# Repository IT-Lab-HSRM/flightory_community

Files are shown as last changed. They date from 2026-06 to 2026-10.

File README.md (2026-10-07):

# ✈️ Flightory Community Hub
### Experience Reports, Troubleshooting & General Help

A community knowledge base for everything Flightory — experience reports, troubleshooting guides, tips, and useful resources, built and maintained by students and enthusiasts.

### 🛠️ Our Story
During our drone project at the **Technical University Hochschule RheinMain**, we built a **Flightory Stallion VTOL** from the ground up. We quickly found that documentation was often insufficient, inconsistent, or scattered across many platforms. This repository was our answer: a structured, community-focused hub where knowledge and practical insights can be shared in one place.

Disclaimer: This is NOT official Flightory Documentation, but Experience gathered from the community <3

## 📁 Repository Structure

| Folder | Description |
|---|---|
| 🎓 [01_HSRM StallionVTOL_Our_Project](./01_HSRM%20StallionVTOL_Our_Project) | Our university project documentation following the build of a Stallion VTOL |
| 💡 [02_Tips, Learnings & Troubleshooting](./02_Tips,%20Learnings%20%26%20Troubleshooting) | Tips, best practices, Bug fixes, workarounds, issues |
| 🌐 [03_Community Projects & Knowledge](./03_Community%20Projects%20%26%20Knowledge) | External contributions & community findings |

> Each folder has its own README with more detail on what goes inside.

## 🔗 External Resources

We include external links when they provide meaningful value.

### 📄 Flightory Manuals
As found in a different GitHub Repo:
[github.com/complexorganizations/flightory-com](https://github.com/complexorganizations/flightory-com)

### 🏢 Official Flightory

| Resource | Link |
|---|---|
| Official Website – LW-PLA Print Settings | [flightory.com/lw-pla-print-settings](https://flightory.com/lw-pla-print-settings/) |
| Facebook Community Group | [facebook.com/groups/flightory](https://www.facebook.com/groups/flightory/) |
| Official Facebook Page | [facebook.com/flightoryuav](https://www.facebook.com/flightoryuav/) |
| Official YouTube Channel | [youtube.com/c/FLIGHTORY](https://www.youtube.com/c/FLIGHTORY) |
| Official Discord | [discord.com/flightory](https://discord.com/channels/1235173288150437929/1277936960970690603) |

### 🎬 Helpful Tutorials on YouTube

- [Flightory Talon 1400 Build Tutorial Part 1](https://www.youtube.com/watch?v=U0Qsgw7TUzI)
- [Flightory Talon 1400 Build Tutorial Part 2](https://www.youtube.com/watch?v=ay6Tz3RohFc)
- [Stallion VTOL Full Build Playlist](https://www.youtube.com/playlist?list=PL0V78eTdTTFGM4ZsZB-8frSqBhW0S1qe1)

Full Beginners Guide Stallion VTOL: 
- [Part 1](https://www.youtube.com/watch?v=75mRBMRqSeE&list=PL8VKXobKCFh9J2dTppRWEMae5zzevURrA)
- [Part 2](https://www.youtube.com/watch?v=D3_zBNBu3qo)
- [Part 3](https://www.youtube.com/watch?v=thHDy3jc1nU)
- [iNav Setup Stallion VTOL](https://www.youtube.com/watch?v=B3aNtYs5-dk)

### 💬 Interesting Reddit Communities

- [r/diydrones](https://www.reddit.com/r/diydrones)
- [r/drones](https://www.reddit.com/r/drones)
- [r/RCplanes](https://www.reddit.com/r/RCplanes)

### 🐙 Interesting GitHub Repos
- [/awesome-drone-engineers](https://github.com/brandonhimpfen/awesome-drone-engineers)

## 🤝 Who Can Contribute?

Everybody is welcome to contribute! 😊

Your Questions, Answers and personal experience can be shared via: 
- Issues
- Pull Requests

For more info see [03_Community Projects & Knowledge](./03_Community%20Projects%20%26%20Knowledge)

## 📝 Source Attribution

Each contribution must include a source reference. This can be helpful to get the content correct. 

**Format:**
```
Source: Personal / Facebook / Discord / Official Docs / Other (with link)
Post/Date (if available)
```

**Examples:**
```
Source: Personal experience, tested on ...
Source: Discord, link ...
Source: Facebook Group "Flightory Community", link: ...
```

## 📌 Notice

This repository is a work in progress, created as part of my bachelor's course at the **Technical University Hochschule RheinMain**. It will grow over time — both through our own findings and through your contributions.

If it looks a bit thin right now, that's expected. Stay tuned, share your experiences, and thank you for your understanding! 🙏

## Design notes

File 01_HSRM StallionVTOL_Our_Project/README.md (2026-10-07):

# 🚁 01 – HSRM StallionVTOL: Our Project

This folder documents our practical course project at the **Technical University Hochschule RheinMain (HSRM)**, where we built a **Flightory Stallion VTOL** system from the ground up.

It serves as a transparent record of our process — including what worked, what didn't, and everything we learned along the way.

Documents in this folder are organized across two practical courses (P1 and P2). 
The prefix in each filename indicates which course it belongs to, making the chronological progression easy to follow.

Our own troubleshooting tips and learnings are of course incoporated in [02_Tips, Learnings & Troubleshooting](/02_Tips,%20Learnings%20%26%20Troubleshooting)

## 📂 What You'll Find Here

- Build process and assembly notes
- Configuration and setup decisions
- Problems we encountered and how we solved them
- Lessons learned and personal takeaways

## 📁 Folder Structure  

| File | Description |
|---|---|
| 📷 [P1_pictures](./P1_pictures) | Pictures used in Part 1 of our documentation |
| 📦 [P1_stl_payload_case](./P1_stl_payload_case) | STL files for the payload box we've designed |
| 📷 [P2_pictures](./P2_pictures) | Pictures used in Part 2 of our documentation |
| 📝 [P1_experience_report](./P1_experience_report.md) | The first part of our journey (Wintersemester 2024/25) summed up |
| 🔗 [P1_links_parts_tutorials](./P1_links_parts_tutorials.md) | Links we found useful |
| 🛒 [P1_shopping_list](./P1_shopping_list.md) | Our shopping list for the first part |
| 📝 [P2_experience_report](./P2_experience_report.md) | The second part of our journey (Summersemester 2025) summed up |
| 📓 [P2_logbook](./P2_logbook.md) | An informal logbook of the second part, a detailed track record |
| 🛠️ [P2_repairguide](./P2_repairguide.md) | A small guide on how to repair the Stallion's tail after a crash |

## 📝 Source

All content in this folder is based on personal experience during the HSRM project.

```
Source: Personal experience, HSRM drone project 2024/25
```

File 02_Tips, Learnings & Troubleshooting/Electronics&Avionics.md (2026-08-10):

# Electronics & Avionics 

## Table of Contents
0. [General](#0-General)
1. [Flight Controller & ESC](#1-flight-controller--esc)
2. [Motors & Servos](#2-motors--servos)
3. [GPS & Receiver](#3-gps--receiver)
4. [Power & Battery](#4-power--battery)
5. [VTX & Camera](#5-vtx--camera)
6. [Thermal Management](#6-thermal-management)
7. [Electronics & Wiring](#7-electronics--wiring)

## 0. General

### No wiring documentation provided by Flightory (hsrm)
**Problem:** Flightory provides no guidance on wiring the electronics — only a note that there is enough space for them.

**Fix:** Use the individual component manuals (FC, ESC, GPS, receiver) to determine pin assignments. The ArduPilot VTOL wiring documentation is the most complete reference available. Community Discord is useful for specific connector questions.

---

### Almost no connectors are compatible out of the box (hsrm)
**Problem:** Nearly every connector in the build either didn't match, was missing, or had the wrong pin order. This affected:
- FC to ESC
- GPS module connector (JST-SH vs JST-GH mismatch)
- Motor cables to ESC
- Battery cables to charger

**Fix:**
- Have a stock of JST-SH, JST-GH, and XT60 connectors ready
- Expect to cut, re-pin, and re-solder most connections
- Cross TX→RX and RX→TX whenever connecting serial devices (GPS, receiver, telemetry)
- Verify pin order against both component manuals before soldering — "plug and play" rarely means what it implies

---

### Cable channels are too narrow for bundled cables (hsrm)
**Problem:** The fuselage cable channels are tight. Several cables broke during routing.

**Fix:** Bundle cables with heat-shrink tubing before routing — this protects individual wires and makes the bundle more rigid and manageable. Do not force cables through channels — if resistance is felt, remove and check for a blockage.

---

### Faulty component on delivery — check everything before assembly (hsrm)
**Problem:** One servo arrived defective and only failed during testing, requiring disassembly and replacement of already-installed parts.

**Tip:** Test all servos, motors, and ESCs on the bench before installation. A servo tester or the FC's output test mode is sufficient — this takes minutes and can save hours of rework.

---

## 1. Flight Controller & ESC

### Motors won't respond despite successful arm in Mission Planner (hsrm)
**Problem:** Mission Planner shows a successful arm status but motors remain completely silent at all throttle inputs.

**Cause:** No physical arm/disarm switch configured on the transmitter. Mission Planner can show "armed" in software while the transmitter has no channel assigned to trigger arming on the FC.

**Fix:** Configure a dedicated arm/disarm switch on the transmitter and link it to the correct ArduPilot arm function in Mission Planner. Once correctly assigned, set the switch to arm — motors should immediately spin up at idle and respond to throttle input.

> This was the single issue blocking all motor control from the previous semester. It took until this semester to identify and cost significant time.

---

### Pitch and roll axes inverted on first flight (hsrm)
**Problem:** After first takeoff, pitch and roll inputs produce the opposite of the expected response — pushing forward pitches backward, etc.

**Fix:** In Mission Planner, invert the relevant RC input channels or set the servo output to "reversed" for the affected axes. Check all axes on the ground before flight using the Mission Planner servo output monitor while moving sticks.

---

### SpeedyBee F405 Wing Mini — bricked after flashing iNAV (fb)
**Problem:** After flashing iNAV (target SPEEDYBEEF405WING), the FC stopped connecting. SpeedyBee app shows "Failed to Communicate with FC." No COM port or DFU visible in iNAV Configurator.

**Fix:** Disconnect the GPS module completely from the FC, then reflash. The GPS appears to interfere with the DFU/connection process on this board.

**Also:** Use **Zadig** to install the correct USB driver (STM32 Bootloader) in Windows if DFU mode isn't being recognised.

---

### SpeedyBee F405 Wing — DFU mode shows as "Unknown Device" (dc)
**Problem:** Holding BOOT button puts FC into DFU but Windows shows "Unknown Device." ImpulseRC Driver Fixer doesn't help.

**Fix:** The FC needs to show as "STM32 Bootloader" in Device Manager. Delete the unknown device, then use **Zadig** to install the correct WinUSB driver. Then retry flashing.

---

### JHEMCU F405 clone — is it compatible? (fb)
**Question:** Can I use a JHEMCU F405 clone instead of the SpeedyBee (which is out of stock)?

**Answer:** Yes, Any F405-class FC flashed with the correct iNAV or ArduPilot target will work the same way.

---

### 4-in-1 ESC current rating — is 50A enough for VTOL? (fb)
**Question:** ESC rated 50A but total current draw at transition showed 93A — is the ESC undersized?

**Clarification:** A 4-in-1 ESC rated 50A means 50A **per motor/channel**, not total. So a 3-motor VTOL on a 50A 4-in-1 = 150A total capacity. The 93A reading is the **total draw across all motors**, which means each motor was pulling ~31A — well within the 50A per-channel rating.

---

### ESC cutting out during transition / crash (fb)
**Problem:** ESC triggered protection cutout at 93A during VTOL-to-fixed-wing transition, causing loss of power and crash. ESC rebooted mid-air (startup beeps heard after crash).

**Possible causes:**
  * **Underpowered/wrong battery voltage** — 1300KV motors designed for 5S–6S being run on 4S won't produce enough thrust and motor will draw more current trying to compensate
  * **Weight** — overweight build means motors work harder at transition
  * **Loose battery connector** — a slightly loose XT60 can cause momentary power interruption that triggers ESC protection
  * **Wiring gauge** — undersized wires cause voltage sag under load

---

### External PDB with current meter for F405 Wing (fb)
**Question:** What external PDB can be used with SpeedyBee F405 Wing to see total amp draw in OSD?

**Answer:** There isn't really a clean external PDB solution that connects a current meter to the F405 Wing. The **F405 Wing already has a built-in PDB with current sensing** — use that. Connect your battery through the FC's power input and configure the current sensor in the flight software.

---

### F405 battery monitoring settings (Matek F405 Wing V2 vs V1) (fb)
**Question:** Are the battery monitoring settings in Mission Planner the same for V2 as V1?

*Note:* ArduPilot docs at: https://ardupilot.org/plane/docs/common-matekf405-wing.html
*(V2 settings not confirmed, check directly with Matek or ArduPilot forums for V2-specific BATT_AMP_PERVLT and BATT_VOLT_MULT values.)*

---

### Motors not spinning in iNAV — arming disabled (dc)
**Problem:** Motors go through boot beep sequence but won't spin. iNAV shows "Arming_Disabled_RC_link."

**Fixes:**
  * Check arming flags in iNAV — look at bottom status bar
  * RC link error = the flight controller doesn't see a radio receiver signal
  * Make sure receiver is bound and connected via correct UART
  * In iNAV Receiver tab, set correct UART and CRSF as connection type
  * Cross RX→TX and TX→RX between FC and receiver
  * Try ArduPilot if iNAV is unfamiliar — easier for first builds according to community

---

### ESC not communicating with FC — motors won't spin (dc)
**Problem:** 4-in-1 ESC connected but FC can't control motors.

**Root cause:** FC wasn't communicating with ESC. Missing telemetry/communication wire, or motor +/- wired backwards.

**Fix:** Check that FC is talking to ESC via correct pins. Swap positive and negative motor wires if motors don't spin. With a 4-in-1 ESC, ensure the communication cable is properly connected, not just the power wires.

---

### UART settings not saving in iNAV (dc)
**Problem:** UART 5 saves but after reboot the setting disappears.

**Fix (self-discovered):** Was using the slider as an on/off switch incorrectly. Check the iNAV documentation for the correct way to enable UARTs. Conflicting inputs can prevent saves.

---

### ESC (Lumenier/BLHeli_32) won't connect to BLHeli Suite (dc)
**Problem:** BLHeli Suite can't read or connect to ESCs.

**Fix:** Download BLHeli Suite from the correct source: https://sequremall.com/pages/blhelisuite32 and make sure you have the correct version. Also requires a **charged LiPo connected to the ESC** during configuration — USB power alone is not enough. Enable BLHeli passthrough in ArduPilot first.

---

### FC smokes / burns during full throttle test (dc)
**Problem:** SpeedyBee F405 Wing smoked during motor test at full thrust with 4S battery.

**Likely causes:**
  * Capacitor wired incorrectly (should be on battery pads, not elsewhere)
  * Poor solder joints — any exposed brass or cold joints can cause shorts
  * Having FC connected to PC via USB while also connected to battery can cause issues

**Fix:** Check all solder joints — exposed brass means a bad joint. Use paste flux to improve soldering. If the gyro chip is damaged the FC may be fried. An SMD soldering station can replace the IC if you have the skills.

---

### Motors pulsing when disarmed (SpeedyBee F405 + 4-in-1 ESC) (dc)
**Problem:** Motors pulse continuously when disarmed. ESC calibration appears to work but pulsing returns.

**Fix:** Set `Q_M_SAFE_DISARM` to 1 to stop pulsing when disarmed. If pulsing continues when armed, switch between DShot 300 and DShot 600 and redo ESC calibration. Community member resolved this by toggling between the two DShot settings.

---

### OSD disappears above 20–30% throttle (dc)
**Problem:** OSD flickers and disappears at higher throttle. Video feed unaffected.

**Cause:** Unfiltered voltage from the ESC causing noise on the OSD chip.

**Fix:** Add electrolytic capacitors to the ESC power pads. 470µF at 16V is a start (got the glitch threshold up to 40%). For a permanent fix on 4S, use 1000–1500µF rated at 25V or 35V (to handle full battery voltage safely). A solid common ground for all components also helps.

---

### Multiple BEC in parallel burned one immediately (dc)
**Problem:** Three BECs connected in parallel to the battery — one immediately burned out.

**Cause:** Multiple BECs in parallel fight each other on the output side due to slight voltage differences between them.

**Fix:** Don't connect multiple BECs in parallel directly. Use a single BEC with enough current capacity. For 6 small digital servos (EMAX ES08 size), a single 3–5A BEC is more than sufficient — actual current draw is much lower than stall current.

## 2. Motors & Servos

### Servo destroyed during testing — constrain movement before first test (hsrm)
**Problem:** During a servo test, a tilt rotor servo moved without input, hit the boom, stripped its gears, and was destroyed within seconds.

**Fix:** Before running any servo test, manually constrain the range of movement — hold the motor mount or temporarily block full travel. In ArduPilot/Mission Planner, set servo min/max limits before sending any test signals. Verify the servo is connected to the correct output channel first.

---

### What servo can I use instead of the recommended one? (dc)
**Answer:** Any servo with similar weight and torque rating will work. If the dimensions differ, you may need to modify the mounting bracket. Community-confirmed alternatives for Stallion:
  * Orbit Eris Digital Servo — 4.7kg, 0.10s, 8.5g metal gear
  * Corona SB9029 — 2.2kg, 0.10s, 12.5g
* Available at: https://alofthobbies.com/

---

### Motor not lifting VTOL — underpowered (dc)
**Problem:** 1300kv motor with 7" propeller can't lift a 2.25 kg VTOL.

**Fix:** Use PropCalc (https://www.ecalc.ch/xcoptercalc.php) to check your power/thrust figures before building. For VTOL, aim for at minimum 1:1 thrust-to-weight ratio at hover throttle. Check motor KV and prop size are matched to your battery voltage. *(See also section 4 regarding 4S vs 6S batteries for 1300KV motors).*

---

### Motor spinning wrong direction (dc)
**Fix:** Swap any two of the three motor phase wires to reverse rotation. For ESC-motor connections, use bullet connectors so you can easily swap wires without resoldering.

---

### Broken servo / servo spinning continuously (dc)
**Problem:** One servo spins continuously and won't hold position after centering attempt.
**Answer:** The servo is likely broken. Servos should spin to a stop position, not continuously. Replace it.

---

### ESC/motor smoking at 40% throttle (dc)
**Problem:** Motor and ESC started smoking at ~40% throttle.

**Possible causes:**
  * Short circuit somewhere — check all wiring for exposed solder pads and missing insulation
  * Cheap ESC with poor real-world ratings
  * Propeller hitting something and stalling the motor causes instant ESC burnout

**Fix:** Ensure all wiring is properly insulated with heatshrink. Add a capacitor on the battery pads. Verify ESC amperage rating matches motor requirements.

## 3. GPS & Receiver

### GPS not connecting — Matek M10Q-5883 + SpeedyBee F405 Wing + iNAV (fb)
**Problem:** GPS LED on, but iNAV shows 0 satellites, 0 total messages, Fix type: None. Ports configured with UART3 → Sensors → GPS, protocol UBLOX.

**Most likely cause:** TX/RX wires crossed incorrectly, or cable pinout incompatible between the two connectors.

**Checklist:**
  1. Confirm GPS TX → FC RX and GPS RX → FC TX (cross the wires)
  2. Verify the cable pinout against both the FC and GPS documentation — ready-made cables often have wrong pin order between JST-SH and JST-GH connectors
  3. Make sure "GPS for navigation and telemetry" is enabled in iNAV Configuration tab
  4. Test outdoors — GPS won't lock indoors

---

### GPS connector mismatch (SpeedyBee F405 Wing + Matek M10Q-5883) (dc)
**Problem:** FC uses JST-SH 1.0 but GPS uses JST-GH 6-pin — connectors don't match.

**Fix:** Insert wires into the GPS-side JST-GH connector and solder the other end directly to the FC. SpeedyBee intentionally provides a GPS cable with bare contacts for this reason. Pin order matters — verify pin-out against both manuals.

---

### GPS satellites = 0 indoors (dc)
* **Problem:** GPS shows 0 satellites when testing indoors.
* **Answer:** Normal — GPS often can't get a fix indoors due to building construction blocking signal. A GPS cold start can take 10–30 minutes on first use while it builds its almanac. After the first fix, subsequent lock-ons are much faster if the module has battery backup. Take it outside for proper testing.

---

### GPS freezing FC / servo outputs dropping to 0 (dc)
* **Problem:** Plugging in GPS causes all servo outputs and receiver channels to show 0 in Mission Planner. Unplugging GPS restores everything.
* **Cause:** Incorrect wiring — GPS pin order differs between brands. Ready-made cables can have wrong polarity.
* **Fix:** Verify pin-out carefully against both the FC and GPS manuals. Don't assume a ready-made cable is correct.

---

### Receiver not being detected by FC (Radiomaster Pocket + Matek R24D) (dc)
* **Problem:** Transmitter and receiver are bound, but FC shows no channel movement.
* **Explanation:** "Bound" only means the radio and receiver are talking to each other — it doesn't mean the FC sees the receiver yet.
* **Fix:** Cross RX→TX and TX→RX between receiver and FC. In iNAV, set the correct UART and choose CRSF as the protocol in the Receiver tab.

---

### ELRS receiver connected but arming disabled (Arming_Disabled_RC_Link) (dc)
* **Problem:** DJI O3 used as receiver on F405 Wing with iNAV — arming flag persists.
* **Fix:** Set the UART that the O3 is connected to for "SmartPort" / serial RX in iNAV configuration. Reference: https://speedybee.zendesk.com/hc/en-us/articles/23350373093787
* After fixing the RC link error, set up arming via a switch: go to the Receiver section in iNAV, use the channel auto-assign feature, and flip the switch you want to use for arming.

---

### TX16S external module power loop above 100mW (dc)
* **Problem:** Radiomaster Nomad TX module gets stuck in power loop when set above 100mW.
* **Answer:** The JR Bay interface is limited to ~100mW. This is a legacy hardware limitation — not a fault. For higher power levels (250mW, 1W, etc.), an **external battery via XT30** is required. The TX16S battery cover has a pre-marked knockout slot for the power lead.

## 4. Power & Battery

### 4S battery not enough for Stallion VTOL with 1300KV motors (fb)
**Problem:** Stallion VTOL with T-Motor F90 1300KV motors on 4S battery can't lift off — needed 100% throttle just to get a few inches up.

**Answer:** 1300KV is designed for 5S–6S. On 4S it doesn't have enough RPM to generate sufficient thrust, regardless of prop size.

**Fixes:**
  * Switch to **6S battery** (most recommended — night and day difference)
  * Or use **5S battery** as a minimum
  * Or change to higher-KV motors suited for 4S

---

### Battery for flight time estimation (fb)
**Rule of thumb:** If you know your cruising amp draw and battery capacity, divide capacity by amp draw for approximate hours.

**Example:** 10,000mAh battery at 4A cruise = ~2.5 hours. Check motor manufacturer specs for estimated cruise current at your voltage/prop combination.

---

### Batteries in wings — is it possible? (fb)
**Answer:** It has been done on other platforms (FX-78, Firefly-6 VTOL) but not practical for Flightory models. The wing profiles are too narrow for even 21700 cells, and the wings aren't designed to carry that structural load. A 3–4+ metre wingspan would be needed before wing batteries make sense.

---

### Wire gauge for VTOL builds (dc)
**Community guidance:**
  * Battery to FC/PDB: minimum **12 AWG** for VTOL, 14–16 AWG for non-VTOL
  * Motor to ESC: the wires that come with the ESC (typically 16 AWG) are fine — it's 3-phase and current is spread. 18 AWG is NOT enough for the recommended motors.
  * Reference: https://oscarliang.com/wires-connectors/

---

### Heavy 6S battery shifts CG dangerously forward (hsrm)
**Problem:** The new 6S 17 Ah battery is significantly heavier than the 4S pack. When mounted in the standard forward battery bay, the CG shifted well beyond the safe forward limit.

**Fix:** Add counterweight at the tail — approximately 350 g was required in this build to bring CG back within range. Alternatively, redesign the battery bay to mount the battery further rearward, or use a lighter 6S option. Always perform a CG test after any significant component change before attempting flight.

---

### 4S battery useful as accessory power source (hsrm)
**Tip:** Once replaced by the 6S pack for flight, old 4S batteries (XT60 connector) can be repurposed to power FPV goggles and a ground cooling fan. No need to dispose of or store them unused.

---

## 5. VTX & Camera

### Walksnail Avatar VTX not powering on (dc)
**Problem:** Walksnail Avatar HD Kit V2 doesn't power up. USB connection does nothing, no folders appear.

**Answer:** The VTX must be powered from the flight battery, not USB. USB will not power it.

**Fix:** Connect VTX power directly to battery pads on the FC (not a BEC output). Some FC BECs don't provide enough current to boot the VTX reliably.

---

### GM3 gimbal not moving (dc)
**Problem:** Walksnail video works but gimbal won't move.

**Fix:** The GM3 gimbal only works when oriented in the same direction as the VTX module. If the gimbal is flipped (e.g. to hang downward), it stops working. Flip both the gimbal AND the VTX module together to maintain orientation.

---

### VTX overheating on the ground (dc)
**Problem:** Walksnail electronics get very hot when not flying (no airflow).

**Fix:** Add a small 5V fan. The SpeedyBee F405 Wing has 4 x LED strip 5V pads that can power a small fan (up to ~0.5A draw). A 20x20mm or 25x25mm 5V fan is sufficient — just light airflow over the VTX heatsink is enough.

**Alternative:** Connect a 24V fan to the balance lead of a 6S battery, or a 12V fan to the 3S portion of the balance lead.

---

### DJI O3 OSD layout in goggles doesn't match Mission Planner setup (dc)
**Problem:** OSD layout keeps jumping around and doesn't correspond to what's set in Mission Planner.

**Fix:** Install WTFOS on both goggles and CADDX unit, then use the MPS DisplayPort on the UART. This resolved the issue.

---

### Lost video signal at 1 mile (Walksnail) (dc)
**Problem:** Video signal lost while flying ~1 mile away from home.

**Answer:** 1 mile (~1.5 km) is within the typical real-world range limit of Walksnail with stock antennas. There are many variables: interference, obstacles, antenna orientation. The community notes that losing signal at 1.5 km with stock setup is not unusual.

**Fix for reported crash:** The VTX was set to only 25mW instead of 700mW. Always verify your VTX power level before flying.

## 6. Thermal Management

### Battery and ESCs dangerously hot after extended hover (hsrm)
**Problem:** After multiple hover flight cycles, battery and ESCs reached temperatures too high to touch safely without protection.

**Cause:** Hover draws sustained high current — far more than forward flight. The 4-in-1 ESC has limited surface area for passive cooling without airflow.

**Fix:**
- Keep hover phases as short as possible — transition to forward flight quickly
- Allow cooling time between flights — do not immediately fly again after the battery or ESC is warm
- Monitor battery temperature as part of post-flight checks
- Plan active cooling (fan) for ground operation

---

### VTX overheating within minutes on the ground (hsrm)
**Problem:** Walksnail Avatar VTX reaches ~93°C within minutes during ground operation, triggering an overheat warning in the goggles. No active cooling on the ground means this happens before every flight.

**Fix:**
- Use a small 5V fan directed at the VTX heatsink during all ground operations — even brief setup time is enough to overheat it without airflow
- Mount the VTX where it receives maximum airflow in forward flight
- Old 4S batteries (no longer used for the drone) work perfectly to power the goggles and a cooling fan on the ground without draining the flight battery

## 7. Electronics & Wiring

### Modular electronics — recommended approach (hsrm)
Based on two semesters of experience, the following modularisation setup worked well and is recommended for future builds:

- **Motors:** Bullet connectors — each motor individually disconnectable without soldering
- **Servos:** Jumper cables to FC — removable without tools
- **Central electronics box:** FC and ESC in a single removable enclosure — full assembly can be pulled out and reinstalled in minutes
- **VTX / receiver:** Mount on a removable rail inside the fuselage — not tape

This approach significantly reduces fault-finding time and makes crash repair much faster. The one area that still needs a clean solution is a proper VTX and receiver mount — tape was used as a temporary fix and is not sufficient.

---

### SD card for error logging — essential, not optional (hsrm)
**Problem:** Two crashes produced no error logs because no SD card was installed in the FC.

**Fix:** Always have an SD card installed in the FC before any flight. In ArduPilot, logging is enabled by default when a card is present. Review logs after every flight — not just after incidents. Logs make root-cause analysis possible and dramatically reduce guesswork.

---

### WiFi connection to Mission Planner (hsrm)
**Tip:** A WiFi connection between the drone and a ground laptop running Mission Planner allows motor tests, servo trim, PFD monitoring, and flight data to be accessed remotely without a USB cable. Useful for pre-flight checks and post-flight data review. A second operator on the laptop is helpful but not strictly required once the setup is familiar.

---

### Real-time FPV video transmission vs onboard recording (hsrm)
**Finding:** Real-time video transmission to the goggles worked in flight, but the Walksnail system does not support simultaneous live transmission and recording to an external device. Onboard recording to an SD card in the camera worked reliably and produced usable footage. Plan storage accordingly — bring enough SD cards.

## 📝 Sources
- (dc) **Discord Group:** [Discord Flightory Group](https://discord.com/channels/1235173288150437929/1277936960970690603) 
- (fb) **Facebook Group:** [facebook.com/groups/flightory/](https://www.facebook.com/groups/flightory/)
- (hsrm) **Own personal experience** Made during Wintersemester 24/25 (HochschuleRheinMain)

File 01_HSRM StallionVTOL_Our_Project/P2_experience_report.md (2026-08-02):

# 🚁 Stallion VTOL – Final Project Report

*HSRM – Avionics Module · Summer Semester 2025*

# *The Dream of (Horizontal) Flight*

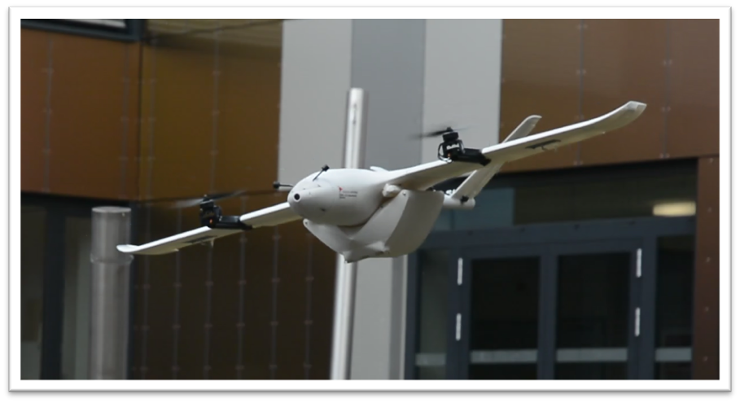
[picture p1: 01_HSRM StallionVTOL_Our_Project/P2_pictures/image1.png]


## Table of Contents

1. [Introduction & Goals](#introduction--goals)
2. [Technical Background](#technical-background)
3. [What We Did & What We Found](#what-we-did--what-we-found)
4. [Summary](#summary)
5. [Open Points & Outlook](#open-points--outlook)
6. [Sources & References](#sources--references)

## Introduction & Goals

This project picked up directly where the previous semester's UAV build left off. The Stallion VTOL was mechanically and electronically complete, but a remaining software issue was preventing actual flight. The goal this semester was to resolve that, get the drone properly airborne, and take the whole system a step further.

**Concrete objectives:**

- **Finalise flight capability** — systematic fault-finding and resolution of the software issues blocking motor control
- **Electronics modularisation** — clean, maintainable wiring with clear separation of functional modules
- **Flight testing & parameter tuning** — structured test flights including tuning for hover stability and transition to forward flight
- **Forward flight** — first controlled forward flight passes to assess horizontal flight behaviour
- **Technical optimisation assessment** — evaluate the real-world impact of our component upgrades (motors, props, CG)
- **Payload flight tests** — determine maximum useful payload through defined load tests, assessing stability and power consumption under load
- **Autonomous flight exploration** — set up PC-based mission planning and run initial automated flight sequences (e.g. waypoint missions)
- **Documentation** — complete technical documentation of all systems, work steps, tests and results as a foundation for future development

## Technical Background

The Stallion VTOL from last semester's project, with the following installed components:

| Component | Specification |
|---|---|
| Motors | T-Motor Velox Victory V3008 1350KV |
| Battery | Zeee 4S LiPo 14.8V 120C 7200mAh XT90 |
| Flight Controller | T-Motor F7 FPV FC |
| ESC | T-Motor F55A Pro II 4-in-1 2S–6S DShot BLHeli32 |
| Servos | GDW DS041MG / Corona Servo CS929MG |
| LEDs | SpeedyBee Programmable 2812 Arm LEDs |
| Propellers | Gemfan CL 8040 Cinelifter 3-blade 8" |
| Transmitter | RadioMaster Zorro ELRS |
| Receiver | Matek ELRS 2.4G Dual |
| FPV System | Walksnail Avatar HD Kit V2 (Dual Antenna) |
| Goggles | Walksnail Avatar HD FPV Goggles L |
| Body | Lightweight PLA (3D printed) |

The project benefited significantly from the support of the IT lab at HSRM — tools, chargers, cables, adapters, and workshop equipment were all on hand.

Picking up from last semester also meant carrying forward hard-won knowledge across electronics, CAD, ArduPilot configuration, ELRS firmware, Mission Planner, and soldering. These skills were essential from day one.

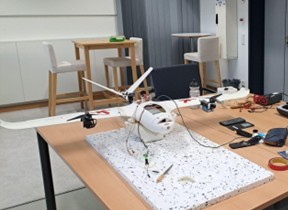
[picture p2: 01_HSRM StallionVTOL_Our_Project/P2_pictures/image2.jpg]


## What We Did & What We Found

### 1. Project Kickoff & Goal Definition
We started the semester by laying out everything that still needed doing. A to-do list was compiled, project goals were defined around modularisation, flight readiness, and stability, and the wiring was tidied up with a rough concept sketch to guide the work ahead.

### 2. Motor Activation — First Technical Breakthrough
The first real hurdle was getting the motors to actually respond. Despite Mission Planner showing a successful arm indication, the motors stayed silent — it turned out a physical arm/disarm switch had never been configured on the transmitter. Once we added the switch and linked it to the correct ArduPilot function, everything clicked into place: the system armed, the motors spun up at idle, and throttle inputs from the transmitter produced the expected response. It was the first time the full control chain had worked end to end.

### 3. Flight Test 1 — First Hover
The drone lifted off for the first time. In the air it was clear that the pitch and roll axes were inverted, which made control awkward, and strong oscillations around the yaw axis made yaw particularly difficult to manage. Despite all of that, the pilot managed to complete several takeoffs and landings without causing any structural damage — a promising start given the state of the parameters.

### 4. Battery & Thrust Analysis
In parallel with the flight work, we ran a proper analysis of the power system to understand what we were actually working with. A luggage scale was ordered for thrust measurements and weight calculations were done to assess whether the planned new battery was even feasible. The results confirmed the system had enough headroom — at 80% throttle the three motors together produce 7.79 kg of thrust at 124.5 A total draw, and cruise at 60% throttle sits around 61.5 A. One important constraint: 100% throttle is only sustainable for roughly 8 seconds, so hover and climb need to be achievable at well below that. With the current 4S setup the all-up weight came to 3.236 kg; switching to the new 6S 17 Ah battery would push that to 4.533 kg — still within the thrust envelope, but leaving less margin.

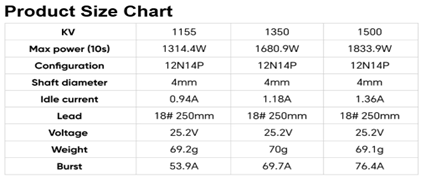
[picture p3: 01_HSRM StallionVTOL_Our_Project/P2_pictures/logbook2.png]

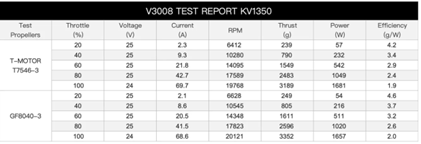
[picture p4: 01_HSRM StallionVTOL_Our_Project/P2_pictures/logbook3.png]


| Condition | Thrust | Current Draw |
|---|---|---|
| 80% throttle (max usable) | 7.79 kg | 124.5 A |
| 60% throttle (cruise) | — | 61.5 A |

| Component | Weight |
|---|---|
| Empty drone | 2.203 kg |
| Cargo case | 0.480 kg |
| Current battery (4S) | 0.553 kg |
| **Current AUW** | **3.236 kg** |
| With new 6S battery (1.85 kg) | **4.533 kg** |

### 5. Flight Test 2 — Parameter Tuning
The second flight was conducted in windy conditions, but the improvement over the first was immediately obvious. The control axes were no longer inverted, yaw behaviour was significantly better, and the drone handled multiple flight cycles without issue. The tuning was clearly working. Two things still needed attention: the tail servos were making audible overload sounds under load, signalling they needed to be replaced, and yaw still drifted slightly back when the stick was released. Post-flight, the battery and ESCs were hot enough that touching them without protection wasn't an option — thermal management was flagged as an open concern.



### 6. CAD Work & Parameter Optimisation
Between flights we used the time to design a landing gear and an enclosure for the ESC and flight controller in Fusion 360. Parameters were also refined further based on what the test flights had shown.

### 7. Flight Test 3 — Two Crashes
The third session started well but ended badly, twice. During a landing the drone simply fell out of the air after switching from QStabilize to QHover at about 2 m — motors cut out completely, the cargo case took the brunt of the impact, and the battery was found warm and unevenly discharged. No structural damage, but the suspected cause was thermal or voltage-related. The second crash was more dramatic: immediately after takeoff in QHover, the drone yawed hard toward the pilot without any stick input and accelerated forward. It hit a bench, the pilot, and a sign stand before the emergency stop was triggered. The most likely explanation was a GPS position mismatch — the pre-flight GPS check had been disabled for test purposes, and the FC may have tried to correct to a position it had never actually confirmed. The outcome was significant structural damage: tail, servo arm, propellers, and wing surfaces all needed attention.
Thankfully the pilot was not injured albeit a bit shaken. 

### 8. Damage Documentation & Safety
Every piece of damage was photographed and logged. We also used this moment to create a proper pre-flight checklist — something that should have existed earlier — to make sure the conditions that led to both crashes couldn't repeat themselves.

### 9. Repair & Modularisation
Damaged parts were removed and either reprinted or reordered. The repair became the natural moment to finally carry out the electronics modularisation we'd been planning. Motors were rewired with bullet connectors so each one is individually disconnectable; servos were connected via jumper cables for easy removal from the FC; and a central electronics box was built to allow the whole electronic assembly to be pulled out and reinstalled quickly. The tail was fully rebuilt, wing surfaces were filled and sanded, and the wiring was re-routed cleanly throughout. 

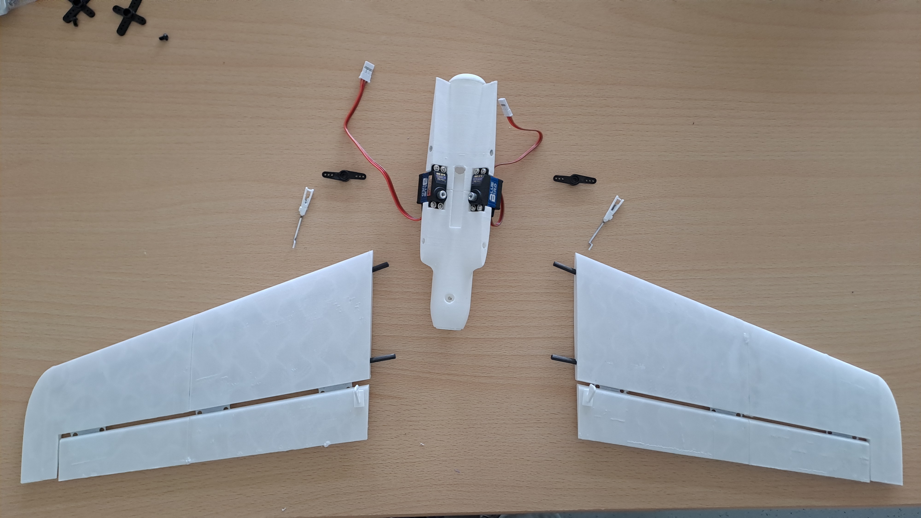
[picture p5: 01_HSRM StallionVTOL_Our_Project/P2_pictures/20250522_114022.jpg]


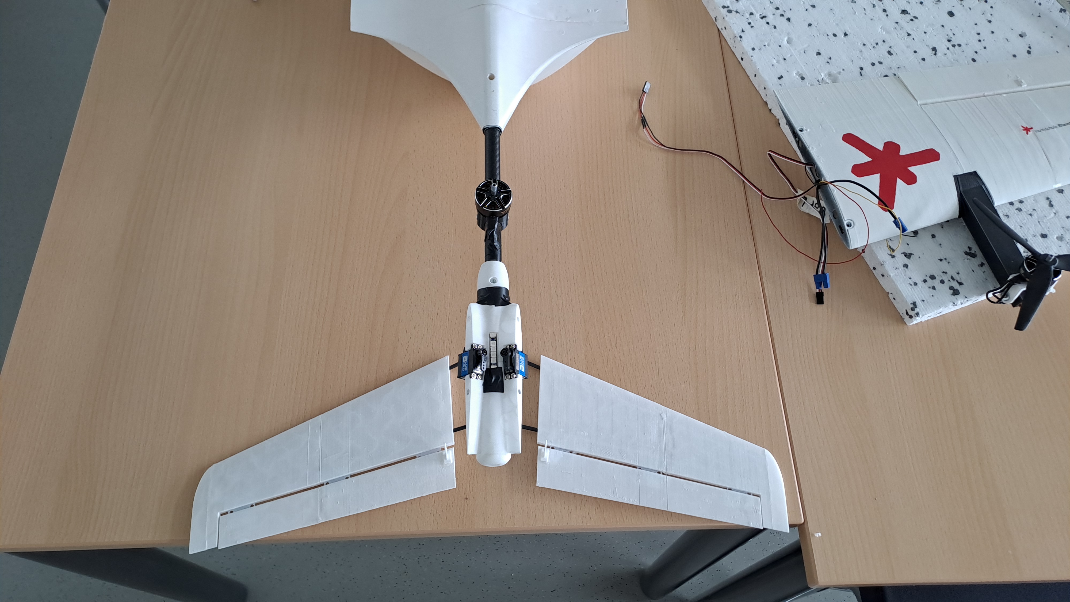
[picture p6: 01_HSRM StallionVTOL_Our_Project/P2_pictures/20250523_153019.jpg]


### 10. VTX Integration
With the new tail assembled and the electronics modularised, the VTX was connected and successfully paired with the FPV goggles. The battery hatch was modified to accommodate the larger 6S battery. One issue that became apparent immediately: the VTX runs extremely hot during ground operation, reaching temperatures that triggered an overheat warning in the goggles within minutes. Active cooling on the ground is essential before any flight. On a more positive note, the older 4S batteries that were no longer needed for the drone turned out to work perfectly as a power source for the goggles.

### 11. Further Build & Electronics Finalisation
The ESC/FC enclosure and landing gear were printed and installed. The VTX, receiver, and camera were all mounted on a removable rail to use the fuselage space efficiently. An SD card for error logging was added to the FC, and a second SD card for video recording was installed in the camera and tested successfully — real-time video transmission wasn't possible, but onboard recording worked well. A WiFi connection to Mission Planner was set up, enabling motor tests, servo trim, and flight data to be accessed remotely from a ground PC.

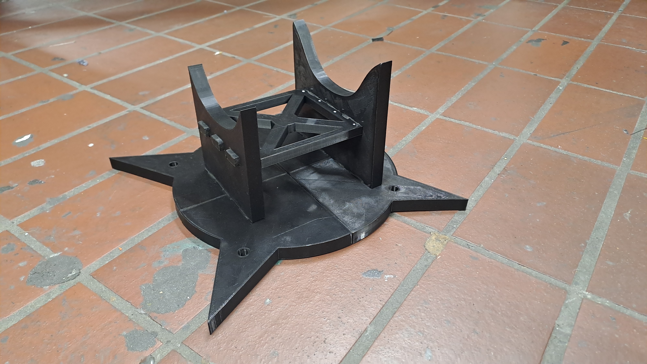
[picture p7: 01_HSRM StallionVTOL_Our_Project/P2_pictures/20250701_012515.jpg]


### 12. New Battery Integration & CG Testing
Integrating the new 6S 17 Ah battery required modifications to the battery bay to get it to fit. The heavier battery shifted the centre of gravity significantly forward, and a CG test confirmed that around 350 g of counterweight was needed at the tail to bring it back within the safe range. Despite the added mass, the drive system had enough thrust to remain viable for flight.

### 13. Flight Test 4 — Model Airfield (Crash)
The fourth test flight, conducted at a model airfield, ended in a crash immediately after takeoff. At first the drone didn't respond to throttle input at all despite a linear increase in the command — then motor output jumped suddenly to 100%, the impulse was far too abrupt for the flight controller to manage, and the drone flipped. Damage was sustained to the tail and parts of the fuselage, though the electronics appeared undamaged. The most likely causes are a combination of the heavy battery shifting the CG to a critical position, a possible software or signal issue between transmitter and receiver, and VTX-related RF interference — the VTX had already run hot before takeoff.

### 14. Repair Documentation
All damage from the airfield crash was documented and a detailed repair guide produced to bring the drone back to its previous state — see [Repair Guide](P2_repairguide.md).

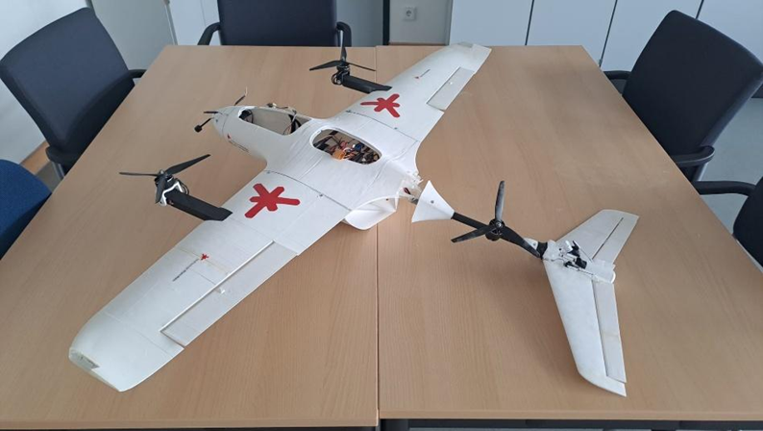
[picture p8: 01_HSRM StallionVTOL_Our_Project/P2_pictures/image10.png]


## Summary

A modular UAV system was developed, built, and tested across multiple flight phases this semester. Key milestones and findings:

**What worked:**
- Motors activated and responding to throttle after arm switch was configured
- Stable hover achieved through parameter tuning — from strong oscillations on the first flight to clean, controlled hover
- Full modularisation of electronics completed
- SD card error logging and video recording both functional
- WiFi Mission Planner connection successful

**What didn't go to plan:**
- Significant thermal load on battery and ESCs during extended hover — active cooling is needed
- Two crashes from thermal overload and GPS-related issues caused structural damage that required a full repair cycle
- Final flight test ended in a flip — likely a combination of weight, CG, thermal interference, and a motor response anomaly

**Where things stand:** The drone is currently damaged and not airworthy. A full repair is required before further flights can be conducted.

## Open Points & Outlook

**Immediate next steps:**
1. Full repair of crash damage (tail, fuselage segment) — see [Repair Guide](P2_repairguide.md)
2. Evaluate whether the current 6S 17 Ah battery is viable or a lighter option should be used
3. Alternatively: structural modifications to handle the battery weight and keep CG stable

**Once repaired:**
- Hover flight tests to verify stability
- Transition to forward flight with VTX/FPV
- First autonomous waypoint missions via ArduPilot Mission Planner

**Longer-term potential:**
- Integration of mission-specific sensors (surveying, monitoring, inspection)
- Design of a V2 airframe optimised for the challenges identified this semester:
  - Larger fuselage for heavier batteries
  - More powerful drive system
  - Additional interior space for payload or sensors

The project has genuine development potential — both in the academic context and toward real-world application. A clear strategic direction for the next team will be essential to make the most of what's been built and learned.

## Sources & References

- [T-Motor Velox V3008 motor data](https://www.mepsking.shop/tmotor-velox-v3008-cinematic-fpv-drone-motor.html)
- [ArduPilot — QuadPlane VTOL Tuning](https://ardupilot.org/plane/docs/quadplane-vtol-tuning-process.html)
- [ArduPilot — Tilt Vectored Yaw Tuning](https://ardupilot.org/plane/docs/tilt-vectored-yaw-tuning.html)
- [ArduPilot — Tilt Rotor Guide](https://ardupilot.org/plane/docs/guide-tilt-rotor.html)
- [ArduPilot — ESC Calibration](https://ardupilot.org/plane/docs/quadplane-esc-calibration.html)
- [ArduPilot — QuadPlane Parameters](https://ardupilot.org/plane/docs/quadplane-parameters.html)
- [ArduPilot — QuadPlane Flight Modes](https://ardupilot.org/plane/docs/quadplane-flight-modes.html)
- [ArduPilot — QuadPlane Tips](https://ardupilot.org/plane/docs/quadplane-tips.html)
- [Flightory — Stallion](https://flightory.com/product/stallion/)
- [Flightory — Stallion VTOL](https://flightory.com/product/stallion-vtol/)
- [YouTube — Stallion VTOL build reference 1](https://www.youtube.com/watch?v=FiyyzRG6oog)
- [YouTube — Stallion VTOL build reference 2](https://www.youtube.com/watch?v=IFvLQy3KrKs)
- [Oscar Liang — Walksnail Avatar FPV Setup](https://oscarliang.com/setup-avatar-fpv-system/)
- [SpeedyBee F405 Wing FC](https://www.speedybee.com/speedybee-f405-wing-app-fixed-wing-flight-controller/)

---

*Source: Personal experience, HSRM Avionics project, Summer Semester 2025*

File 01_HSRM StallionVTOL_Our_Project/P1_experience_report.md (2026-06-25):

# 🚁 Building the Stallion VTOL – Our Experience Report

*O. Alobaid, M. Daoud Agha, C. Diffenhard, O. Weigelt*

*HSRM – Unmanned Aerial Vehicles Module · Winter Semester 2024/2025*

## Table of Contents

1. [The Idea](#the-idea)
2. [What Flightory Gives You](#what-flightory-gives-you)
3. [Our Optimizations](#our-optimizations)
4. [How We Approached the Build](#how-we-approached-the-build)
5. [Assembly – What Actually Happened](#assembly--what-actually-happened)
6. [Challenges During Construction](#challenges-during-construction)
7. [Electronics Assembly](#electronics-assembly)
8. [Programming with ArduPilot](#programming-with-ardupilot)
9. [Ground Test Results](#ground-test-results)
10. [Final Thoughts](#final-thoughts)
11. [Thanks](#thanks)

## The Idea

We are four students who set out to build a 3D-printed Stallion VTOL drone based on Flightory's design — but not just replicate it. From the start, we wanted to push it further. Our main goal was to increase the drone's payload capacity, and to do that we designed a cargo case that can be transported securely beneath the aircraft. This meant rethinking parts of the structure, optimizing several components, and dealing with a lot of challenges we didn't fully anticipate going in.

## What Flightory Gives You

The Stallion VTOL is a tiltrotor drone built on a tricopter layout — two tilting front motors and one fixed rear motor. It's made from lightweight materials like LW-PLA and PETG, spans 1,340 mm, measures 990 mm in length, and cruises at 60–70 km/h with a takeoff weight of 2,000–3,000 g according to Flightory.

Flightory provides STL and STEP files for printing, a build guide, and a recommended parts list:

| Component | Recommendation |
|---|---|
| Motors | Emax ECOII 2807 1300KV or T-Motor F90 1300KV |
| Propellers | 7×4, 7×5, or 7×6 (2× CCW, 1× CW) |
| Servos | PowerHD 1810MG or GDW DS041MG |
| ESC | Emax Formula 45A BLHeli32 or Lumenier 51A |
| Battery | 4S Li-Ion max. 4S3P 10.5 Ah or comparable LiPo |
| Lighting | WS2812 ARM LED strips |
| Bearings | 3×8×4 mm flanged bearings ×2 |
| Hardware | M3 screws, nuts, washers |

We didn't stick to all of these — more on that below.

## Our Optimizations

### Cargo Case
We designed a case in Autodesk Fusion 360 that slides onto a rail system we modeled directly into the fuselage. The whole thing is 3D printed to keep it as light as possible while still being structurally solid.

### Motors
We went with more powerful motors — 23.4 g heavier per unit than the recommended ones, but delivering 621.9 W more power each. The extra current draw is compensated by the upgraded battery.

### Battery
Our batteries are 90 g heavier than the standard option but offer 2,200 mAh more capacity and a 20C higher discharge rate. The idea was to maintain decent flight time despite the added weight of the payload.

### Propellers
We swapped the 7-inch 2-blade props for 8-inch 3-blade variants. Three blades give better stability — important when carrying cargo — and the larger diameter adds meaningful thrust. The slight increase in drag is negligible compared to the gain.

### ESC
We chose a 4-in-1 ESC to save weight and free up space inside the fuselage. The compactness makes a real difference when you're trying to fit everything inside.

### Servos
High-torque servos were a must with the larger motors and propellers, especially given the aerodynamic loads on the tilt mechanism.

### FPV Camera
We added an optional FPV camera — a cost-effective alternative to the suggested model that does the same job.

> For the full parts list with prices and weights, see [P1_shopping_list.md](P1_shopping_list.md)

> Further Links see [P1_links_parts_tutorials.md](P1_links_parts_tutorials.md)

## How We Approached the Build

We kicked things off with a brainstorming session to plan out the optimizations and divide up the work. Here's roughly how it unfolded:

**Preparation** — 3D files were imported into Fusion for analysis while components were being sourced. Once we placed the order, we started adapting the 3D models to include the cargo case and rail system. Unmodified parts were sliced in Cura and BambuStudio in parallel.

**First assembly** — Once the first prints came off the bed, we started fitting parts together and gluing them. 3D printing inaccuracies showed up almost immediately and required a lot of manual correction — filing, drilling, cutting, the works. More on that in the challenges section.

**Electronics installation** — After the fuselage, wings, and tail were done individually, we moved on to servos and motors. Cables were extended with crimp connectors and routed through the channels. While waiting for the remaining components to arrive, we primed and painted the drone.

**Programming** — Once everything was installed, connected, and soldered, we programmed the flight controller using ArduPilot and ran ground tests.

## Assembly – What Actually Happened

After printing all the parts and weighing them, we laid everything out for a first overview. Then the gluing started.

<p align="center">
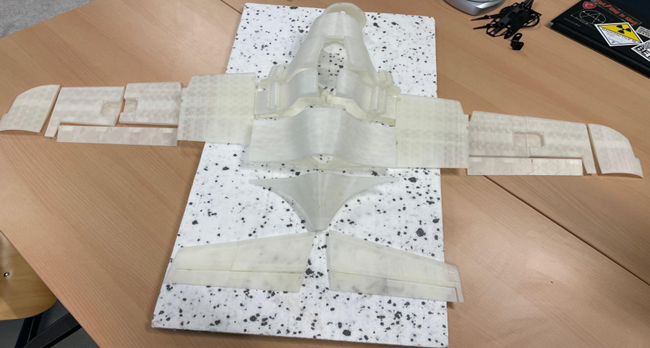
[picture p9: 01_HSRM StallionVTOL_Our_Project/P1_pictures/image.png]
  
</p>

The fuselage went together following Flightory's instructions — but printing inaccuracies showed up right away. A lot of manual reworking was needed before things actually fit. The carbon tubes then had to be cut and sized, and the tail fins and wings were test-fitted before being properly attached.

<p align="center">
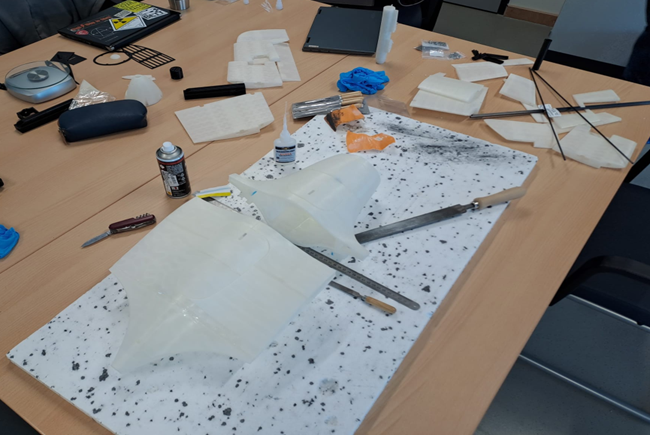
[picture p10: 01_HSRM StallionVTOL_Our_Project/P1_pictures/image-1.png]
  
</p>

Servo and motor installation came next. We had to shorten parts and drill extra holes for cable routing. Once cables were extended and routed, the control surfaces were attached using polyester hinges and eventually linked to the servos via small metal push rods.

<p align="center">
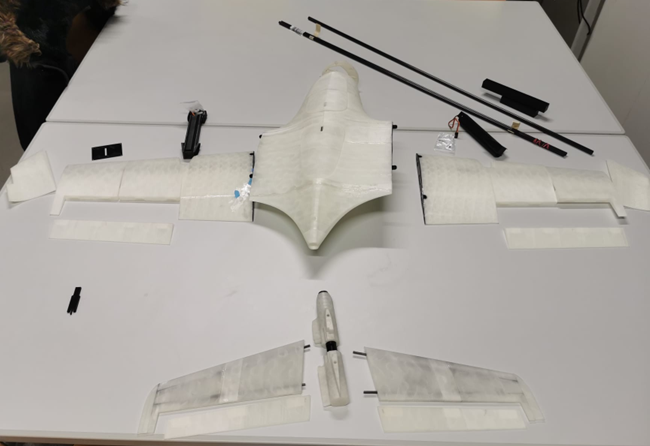
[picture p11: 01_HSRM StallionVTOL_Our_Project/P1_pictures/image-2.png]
  
</p>

Since the flight controller and ESC hadn't arrived yet at this point, we used the downtime to paint. Motors and servos were masked off, the drone was primed, and a matte white coat was applied. The university logo was stenciled onto the wings and degree program stickers went on in a few spots.

<p align="center">
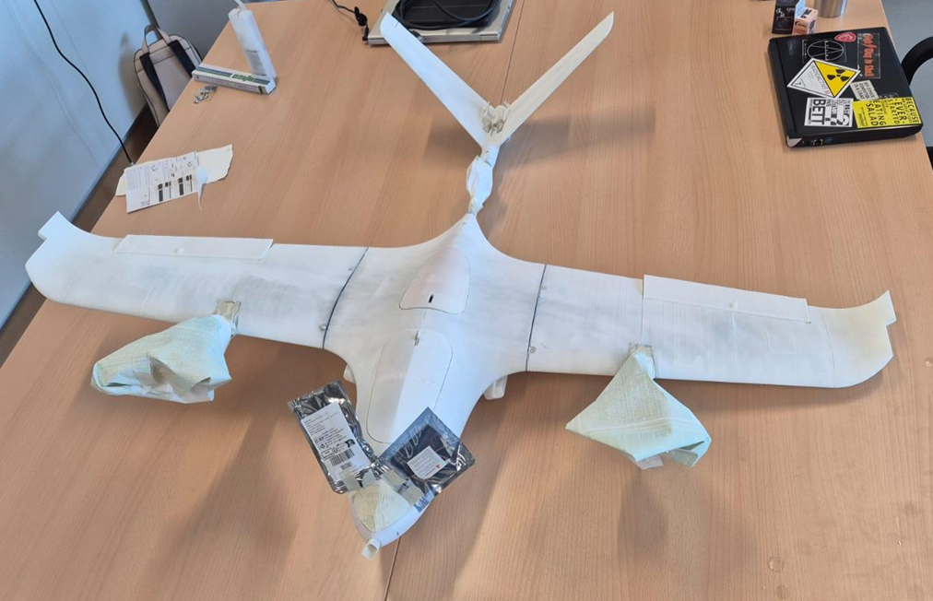
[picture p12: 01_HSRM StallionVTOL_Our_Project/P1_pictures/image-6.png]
  
</p>

<p align="center">
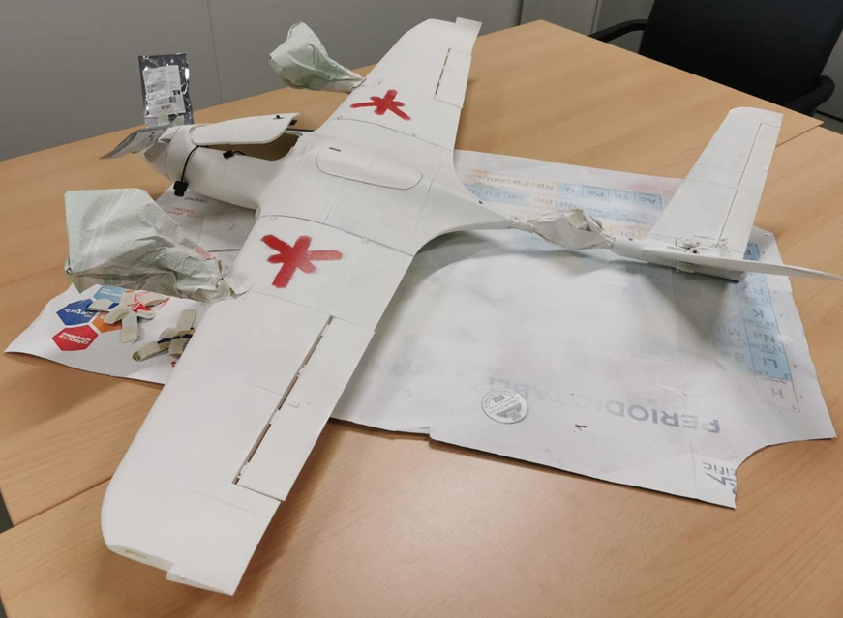
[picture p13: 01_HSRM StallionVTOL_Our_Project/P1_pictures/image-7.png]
  
</p>

## Challenges During Construction

Honestly, we ran into issues almost constantly. Some caused real delays.

**STL vs STEP files** — Flightory only provides some parts as STL files, not the editable STEP format. Getting these into CAD for modification took multiple steps: import as mesh → repair the mesh → convert to a solid body → manually fix surface irregularities. Not the end of the world, but time-consuming.

**Payload rail design mistake** — When we added reinforcing struts inside the fuselage for the rail system, we didn't notice they were blocking where carbon tubes needed to pass through. Only caught it after printing. Holes had to be drilled post-print.

**3D printing inaccuracies** — This was probably the single biggest time sink. Parts that didn't fit right had to be re-glued, and separating CA-glued parts without breaking them is genuinely difficult. Some parts had to be reprinted entirely. Nearly every hole and channel needed post-processing before components would fit.

**The build guide** — Flightory's instructions are... thin. Complex steps like connecting flight controls with hinges and servos are sometimes described in a single sentence with no photos. You spend a lot of time guessing.

**Screws and bearings** — No screw lengths are specified anywhere, so you're just trying different ones until something works. Ball bearings for the motor mounts aren't mentioned at all until you're mid-build and suddenly need them for the next step.

## Electronics Assembly

With the bearings finally in hand, the servos and tilt motor assemblies could be fully completed. Motor mounts were screwed to the booms, connected to the servos, and attached to the wings. 

<p align="center">
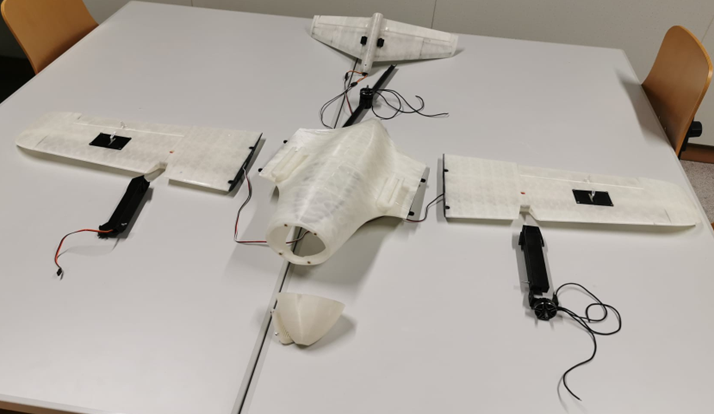
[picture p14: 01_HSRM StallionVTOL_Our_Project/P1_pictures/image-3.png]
  
</p>

Cables for motors and servos were extended to reach the center section. Servo cables plug straight in; motor cables needed crimp connectors. Everything was then fed through the channels and the full wiring harness came together inside the fuselage.

<table>
<tr>
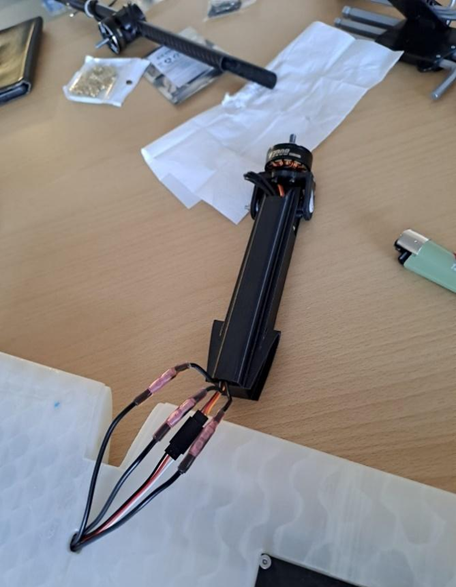
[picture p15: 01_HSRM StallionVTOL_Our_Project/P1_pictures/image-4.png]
<td></td>
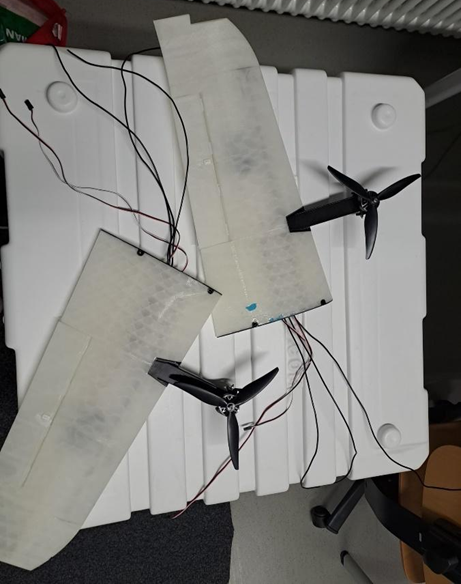
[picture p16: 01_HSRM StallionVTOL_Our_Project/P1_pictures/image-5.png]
<td></td>
</tr>
</table>

The GPS/compass module, camera receiver, and RC receiver were connected to the flight controller. The ESC was soldered to the battery, FC, and motors as required. 

<p align="center">
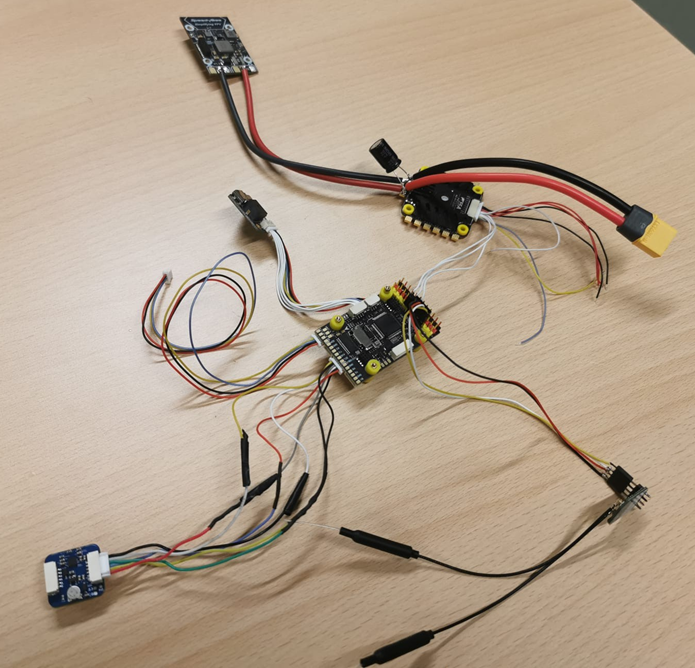
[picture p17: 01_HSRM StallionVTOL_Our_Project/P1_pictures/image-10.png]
  
</p>

Control surfaces and servos were linked via pushrods. LED cables were extended and connected.

<p align="center">
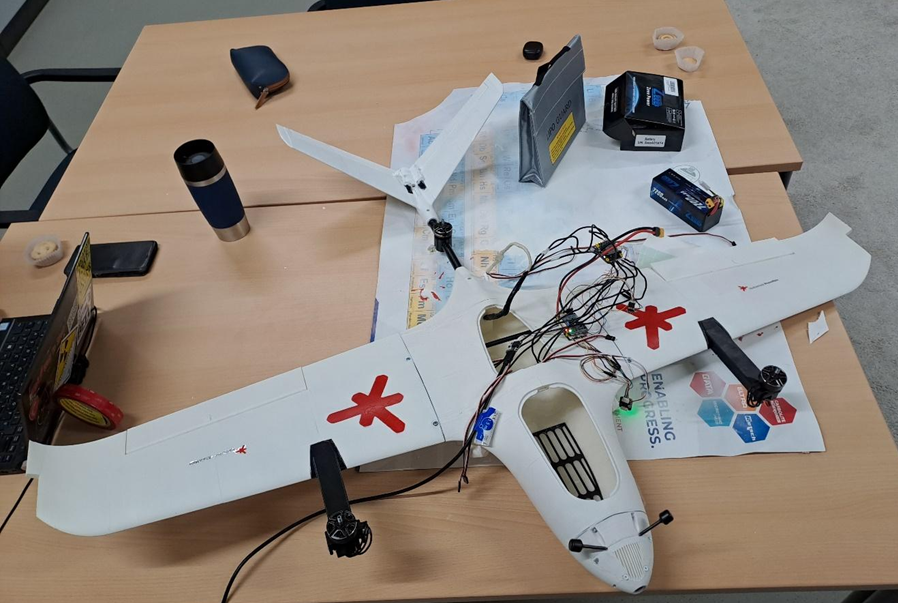
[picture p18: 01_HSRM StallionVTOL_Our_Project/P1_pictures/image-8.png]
  
</p>

### Challenges
---

**No wiring documentation** — Flightory provides zero guidance on how to wire the electronics. The only mention is that the drone has enough space for them.

**Barely any online resources** — Building a VTOL from scratch is niche enough that helpful documentation is essentially nonexistent.

**Component incompatibility** — Nothing is standardized. Most connectors didn't match, or were missing entirely. Plugs had to be cut, wires re-soldered in crossed configurations to get the correct pin assignments. Even the battery cables were incompatible with standard chargers. The FC was sold as "plug and play" — a term we now interpret very loosely.

**Cable channels** — Too narrow. Several cables broke during routing and had to be replaced. We ended up bundling everything with heat-shrink tubing to make it manageable.

**Faulty servo on delivery** — One servo arrived defective, had to be swapped out and re-cabled.

## Programming with ArduPilot

The FC shipped with INAV, so the first step was flashing ArduPlane to enable VTOL behavior. After that it was connected via USB-C to Mission Planner.

Parameters were configured and written to the controller. Then we headed to the university courtyard for sensor calibration — GPS needed an open sky, and the compass had to be calibrated away from interference. That part actually went smoothly and felt like a small victory.

<p align="center">
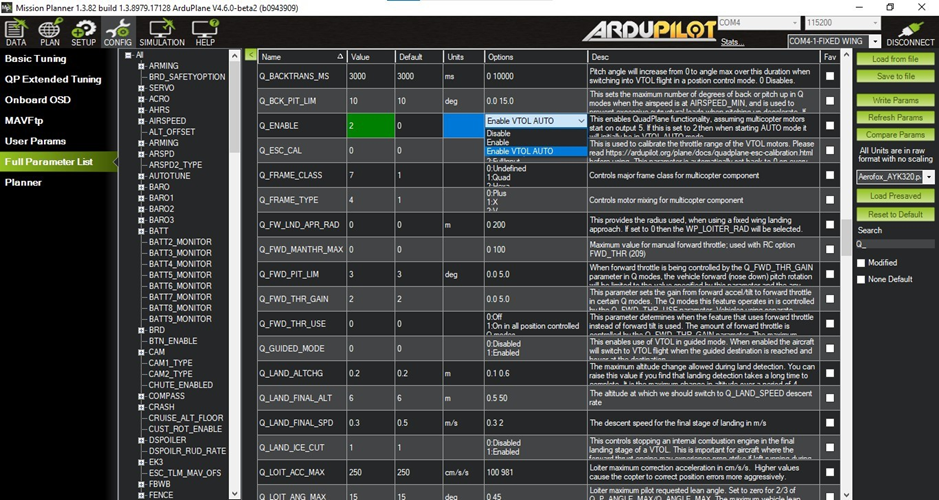
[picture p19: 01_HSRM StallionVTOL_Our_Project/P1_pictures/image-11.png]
  
</p>

<p align="center">
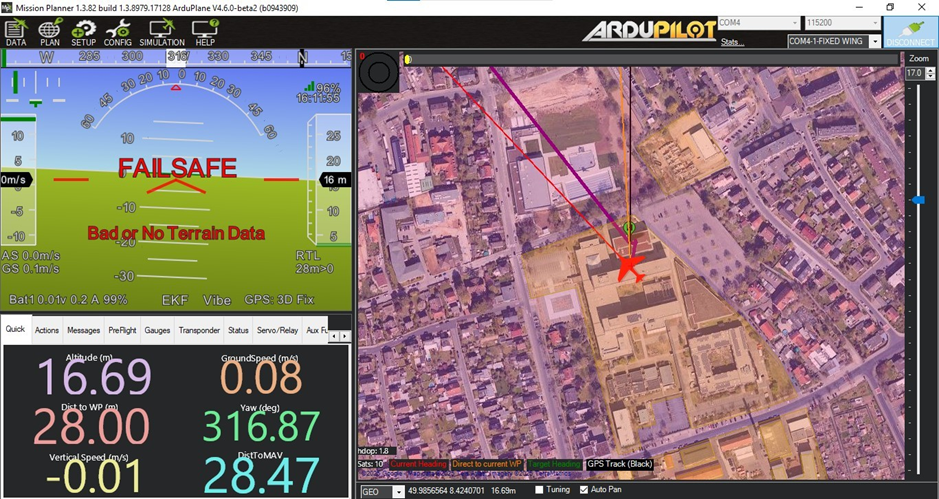
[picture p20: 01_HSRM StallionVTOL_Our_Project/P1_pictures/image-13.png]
  
</p>

Servo outputs were assigned, connected to the correct FC pins, and tested using a custom-built servo tester from the IT lab (thanks Mr.H!).

<p align="center">
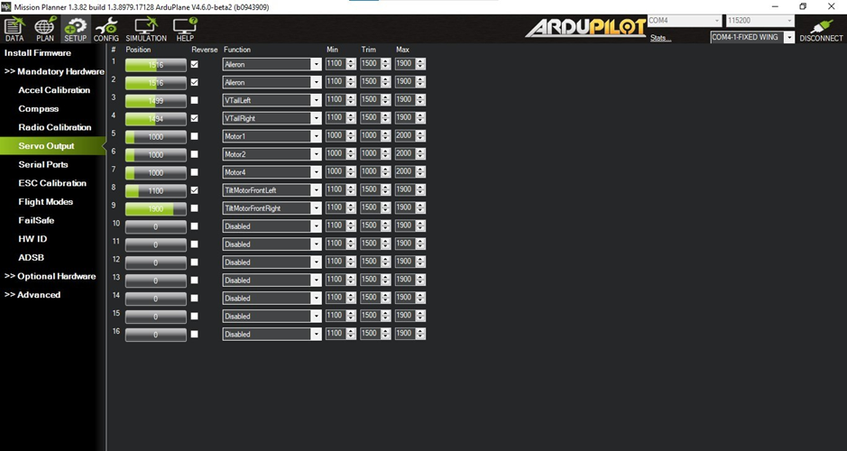
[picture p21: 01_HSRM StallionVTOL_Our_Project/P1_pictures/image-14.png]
  
</p>

The RC transmitter and receiver were both flashed with the latest EdgeTX and ELRS firmware, paired with a shared passcode, and connected automatically on power-up.v

<p align="center">
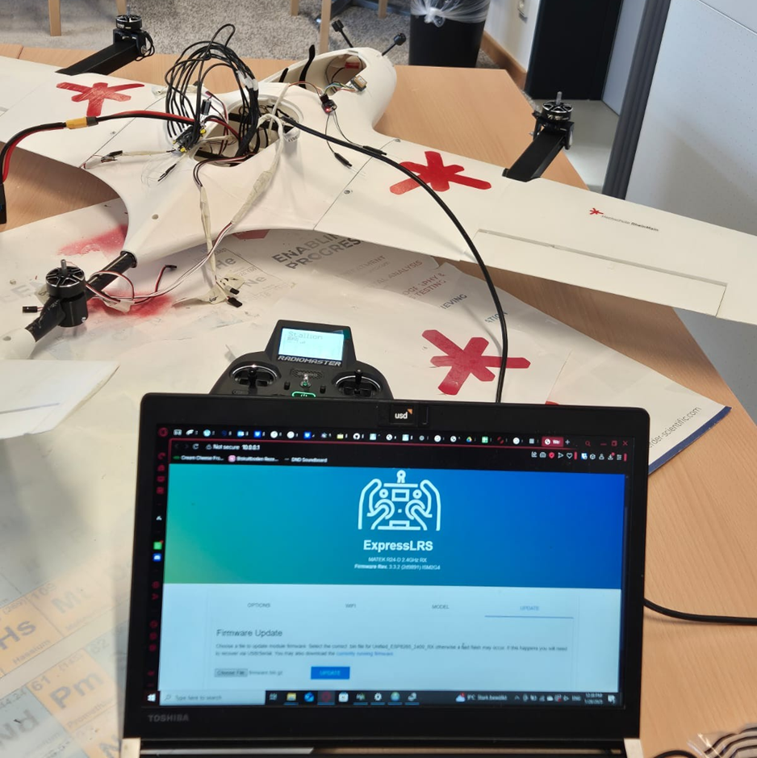
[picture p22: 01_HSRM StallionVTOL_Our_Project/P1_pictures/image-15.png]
  
</p>

Control surface testing went well — V-tail, ailerons, and tilt rotors all responded correctly. The motors, unfortunately, still couldn't be controlled at this point. The IT lab was closing that evening and the report deadline was the same night, so we had to stop there.

### Programming Challenges

**INAV ≠ ArduPilot** — The FC is sold as ArduPilot-compatible, but it ships with INAV and can't be directly flashed with ArduPilot. You have to flash ArduPilot via the INAV Configurator first. This isn't documented anywhere.

**11 hours chasing a firmware bug** — QuadPlane parameters simply didn't work and the ESCs were stuck in standby beeping constantly. We tried everything: different firmware versions, different pins, multimeter measurements, BLHeli32 Suite, parameter changes. Nothing worked that day.

The next day we tried the unstable firmware version — and everything appeared immediately. The parameters had apparently just been removed from the stable release. Not documented anywhere. A day of work lost on something that took minutes to fix once we knew.

**DSHOT "not supported"** — The FC manual said DSHOT1200 wasn't supported. After extensive digging, we found it's actually available and just needs to be enabled via a parameter. The manual was simply wrong.

**RC firmware update** — The official GitHub instructions for updating the RC firmware didn't work. We eventually succeeded by doing a Wi-Fi update instead — figured that out ourselves.

**Servo self-destructed** — During a servo test, one tilt rotor servo moved without any input, hit the boom, stripped its gears, and was completely destroyed within seconds. Our last spare had to be installed.

## Ground Test Results

**Flight control** — Works. Ailerons and V-tail move correctly via the remote. The tilt rotors respond to commands (though full tilt behavior needs airspeed to verify). Automatic stabilization kicks in when you tilt the drone by hand. LEDs indicate status correctly.

**Motors and ESC** — Unresolved at the time of the deadline. We'll keep working on it, just not documented here.

## Final Thoughts

This was a genuinely challenging project that pushed us in directions we didn't expect. The hardware is exciting, but the reality is that documentation — from Flightory, from component manufacturers, from the ArduPilot ecosystem — is often patchy, outdated, or just missing. A big part of the project ended up being detective work.

What we built: a structurally complete, painted, and largely functional Stallion VTOL with a custom payload rail system and cargo case, all sensors calibrated, flight controls working, tilt rotors responding. The motor/ESC issue is the remaining open thread.

What we took away: hands-on experience across mechanical assembly, electronics integration, firmware flashing, CAD modeling, and embedded systems troubleshooting.

<p align="center">
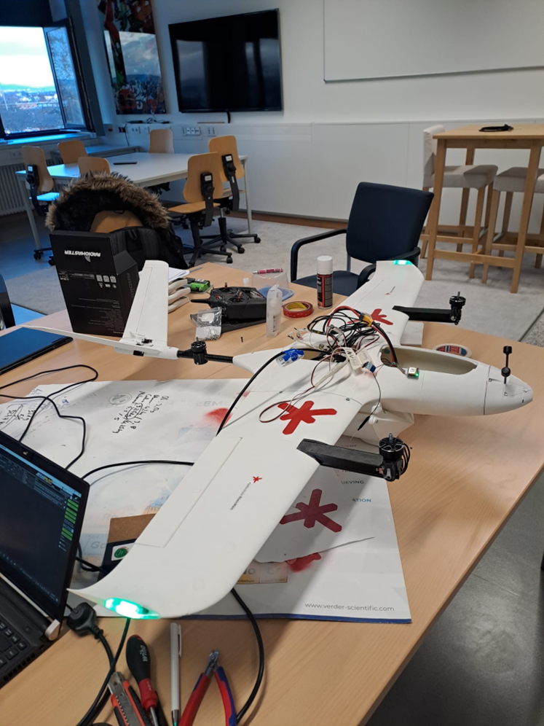
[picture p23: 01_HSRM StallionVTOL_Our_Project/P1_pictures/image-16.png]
  
</p>

---

## Thanks

To everyone at HSRM who supported this project — lecturers, IT lab staff, and fellow students.

## 📝 Source
Personal experience, HSRM UAV project, Winter Semester 2024/2025*

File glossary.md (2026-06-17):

# 📖 Glossary

A reference guide for common terms used in fixed-wing and VTOL drone building, FPV flying, 3D printing, and flight electronics.

| Term | Description |
|---|---|
| **Airframe** | The main structure of the aircraft — fuselage, wings, and tail. |
| **Airspeed Sensor** | Measures how fast the plane is moving through the air (not GPS speed). |
| **Autotune** | Automatically adjusts control gains for optimized flight behavior. |
| **Barometer (Baro)** | Measures altitude via air pressure. |
| **BEC (Battery Eliminator Circuit)** | Supplies power to the flight controller and servos from the battery. |
| **Brim / Raft** | Extra printed material added around the base of a print to improve bed adhesion. |
| **CA** | Cyanoacrylate — it's the chemical name for super glue. |
| **CG (Center of Gravity)** | The balance point of the aircraft — crucial for stable and predictable flight. |
| **CRSF (Crossfire)** | Protocol used by the TBS Crossfire system. Very fast and low-latency, with telemetry support and extended features. |
| **Dihedral** | The upward angle of the wings from the center, used to improve passive stability. |
| **Diversity** | A dual-antenna system that automatically selects the stronger signal source. |
| **DVR (Digital Video Recorder)** | Records the FPV video feed — often built directly into goggles. |
| **Elevon** | A control surface that acts as both elevator and aileron. Common in flying wing designs. |
| **ELRS (ExpressLRS)** | Open-source, ultra-fast, long-range RC protocol. Becoming the go-to standard in FPV — low latency, high refresh rate, telemetry included. |
| **ESC (Electronic Speed Controller)** | Controls the motor's speed based on signals from the flight controller. |
| **Failsafe** | A safety mode triggered automatically by signal loss or critical errors. |
| **FC (Flight Controller)** | The onboard computer that manages sensors, stabilization, and automation. |
| **Fixed-Wing** | A type of aircraft with stationary wings, as opposed to multirotor drones. |
| **FPV (First Person View)** | Flying using a live video feed from an onboard camera. |
| **G-code** | Instructions generated by slicer software to control a 3D printer's movements and extrusion. |
| **Goggles** | Head-mounted display used for FPV flying. |
| **GPS** | Provides real-time location, altitude, and heading data. |
| **Gyro / IMU (Inertial Measurement Unit)** | Measures rotation, pitch, and movement — the core of any flight controller. |
| **Infill** | The internal structure of a 3D print, expressed as a percentage and pattern (e.g. 15% honeycomb). |
| **Latency** | Time delay between camera capture and display in an FPV system. Lower is always better. |
| **Layer Height** | The thickness of each individual printed layer (e.g. 0.2 mm). |
| **LW-PLA / LW-ASA** | Lightweight foaming filaments specifically designed for RC aircraft — very low density once printed. |
| **Nozzle** | The tip of the hotend through which filament is extruded during 3D printing. |
| **OSD (On-Screen Display)** | Overlays live flight data (altitude, voltage, speed, etc.) onto the FPV video feed. |
| **PID** | Control loop parameters (Proportional, Integral, Derivative) that determine how the aircraft responds to inputs and disturbances. |
| **Print Bed / Build Plate** | The surface on which 3D objects are printed. |
| **Pusher** | A motor mounted at the rear of the aircraft, pushing it forward. |
| **Retraction** | The pullback of filament during non-print moves to prevent stringing or oozing. |
| **RSSI (Received Signal Strength Indicator)** | Indicates the quality of the RC link signal. |
| **RX / TX** | Receiver (on the aircraft) / Transmitter (in your hands). |
| **Slicer** | Software that converts 3D models into G-code for the printer (e.g. OrcaSlicer, Cura, BambuStudio). |
| **STEP (Standard for the Exchange of Product Data)** | An editable CAD file format — used when you need to customize a model before printing. |
| **STL (Stereolithography)** | A 3D model file format used for slicing and printing. Not directly editable in most CAD tools. |
| **Supports** | Temporary printed structures that support overhanging parts of a model during printing. |
| **Telemetry** | Sends live flight data (altitude, voltage, GPS, etc.) to a ground station in real time. |
| **Tractor (Puller)** | A motor mounted at the front of the aircraft, pulling it forward. |
| **V-tail** | A tail configuration shaped like a "V", combining elevator and rudder control into two surfaces. |
| **VRX (Video Receiver)** | Receives the FPV video signal transmitted from the drone. |
| **VTX (Video Transmitter)** | Sends the FPV video signal from the drone to goggles or a screen. |
| **Warping** | Curling or lifting of a 3D print caused by uneven cooling during the print process. |
| **Wing Loading** | The ratio of aircraft weight to wing area. Lower wing loading means more efficient and stable flight. |
| **Z-hop** | A small upward movement of the nozzle during travel moves to avoid hitting already-printed parts. |

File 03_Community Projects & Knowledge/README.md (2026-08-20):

# 🌍 03 – Community Projects & Knowledge

This folder is for **you** — the community. Share your own Flightory builds, findings, guides, and questions here.

Whether you're a student, hobbyist, or experienced builder, your experience is valuable to others.

## 📂 What You'll Find Here

- Personal build reports and project showcases
- Community-sourced guides and how-tos
- Open questions and answers
- Findings from Facebook, Discord, Reddit, and beyond

## 🤝 Contribute

This folder lives and grows through community contributions. Feel free to:

- Open an **Issue** to ask a question or suggest a topic
- Submit a **Pull Request** with your own report or guide
- Share findings from the Flightory Facebook group, Discord, or Reddit

Please include a source reference with each entry:

```
Source: Personal experience, tested on ...
Source: Discord, link: ...
Source: Facebook Group "Flightory Community", link: ...
```

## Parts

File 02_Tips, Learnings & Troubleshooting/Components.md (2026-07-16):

# Components

## Table of Contents
1. [Component Choices & Optimisations](#1-Component-Choices--Optimisations)
2. [Sourcing & Alternatives](#2-Sourcing--Alternatives)

## 1. Component Choices & Optimisations

### Motors — upgraded for payload capacity (hsrm) 
Standard recommendation is Emax ECOII 2807 1300KV or T-Motor F90 1300KV. The HSRM team used more powerful motors: +23.4 g per unit but +621.9 W power each. The additional current draw is compensated by an upgraded battery.

**Note:** Higher-KV or higher-power motors require matching ESC current ratings and a higher-capacity battery. Check motor/prop thrust tables against your expected AUW before committing.

---

### Props — 8" 3-blade instead of 7" 2-blade (hsrm) 
**Why:** Three blades give better stability under load (important when carrying cargo), and the larger diameter adds thrust. The slight drag increase is negligible against the thrust gain.

**Consideration:** Larger props need more ground clearance and may require minor boom geometry changes depending on your build.

---

### ESC — 4-in-1 saves weight and space (hsrm) 
A 4-in-1 ESC is noticeably more compact than three individual ESCs and simplifies the wiring harness significantly. Worth it on a build where fuselage space and weight are both constrained.

**Note:** A 4-in-1 ESC current rating is per channel (per motor), not total. A 50A 4-in-1 on a 3-motor VTOL = 150A total capacity.

---

### Battery — upgraded for payload and flight time (hsrm) 
Standard: 4S Li-Ion max 4S3P 10.5 Ah. HSRM build: +90 g but +2,200 mAh capacity and +20C discharge rate.

**Tradeoff:** Heavier battery compensates for heavier motors and props while maintaining flight time. If not carrying payload, the standard battery is the better choice for AUW.

---

### Build time estimate (hsrm) 
For four people working in parallel across CAD modification, printing, assembly, electronics, and programming: allow significantly more time than the build guide implies, especially if:
- Any parts need CAD modification
- You encounter connector incompatibilities (likely)
- Firmware issues arise (likely)
- Any parts need reprinting

> "This was a genuinely challenging project that pushed us in directions we didn't expect."

## 2. Sourcing & Alternatives

### GPS alternatives (Matek M10Q-5883 out of stock)

**Recommendations:**
- Look for any **M10** chipset GPS (current generation, faster acquisition than older M8) with **QMC5883L or 5883** compass
- FlyFishRC Positioning M10QMC-5-8-83L Module (Amazon)
- SEQURE QMC5883L 10th Generation (Amazon)
- https://rotorriot.com/products/m10q-5883-gnss-gps-compass-module
---

### CA glue — thin vs medium vs thick
**Question:** Parts list says thin CA but links to medium.

**Community consensus:** Any CA viscosity works. Thin penetrates gaps well. Medium and thick give more working time and fill small gaps. Multiple community members successfully use thick CA.

---

### Print bed surface options
**Community recommendations:**
- **Smooth PEI + glue stick** — most recommended for LW-PLA
- **Textured PEI** — works for LW-ASA but releases poorly; needs glue stick or specialty adhesive spray
- **Adhesive spray** (3DJake AdheEasy) — strong adhesion, sometimes too strong — heat bed to 90°C after print to release
- **Painters tape on smooth PEI** — also works well

---

### Battery options — Li-ion vs LiPo
**Community advice:**
- Start with **LiPo** — known behavior, easy to find quality cells
- Li-ion offers longer flight times but has lower burst current — risky on high-draw VTOL builds
- Pre-made Li-ion packs from AliExpress frequently lie about capacity — DIY is the way if you want Li-ion
- Quality cell source: **nkon.nl** (Europe) — honest specs, competitive pricing for Samsung, EVE cells

---

### Painting / protecting LW-PLA parts

**Recommendations:**
- **Acrylic spray paint** — any acrylic will harden and strengthen the surface
- **Enamel spray** — stronger hardening effect than acrylic
- **Epoxy enamel** (e.g., Duplicolor, Rust-Oleum acrylic enamel) — best protection, also helps with UV resistance for outdoor flying
- Do NOT let the plane sit in direct sunlight — LW-PLA softens in heat

## 📝 Sources
- (dc) **Discord Group:** [Discord Flightory Group](https://discord.com/channels/1235173288150437929/1277936960970690603) 
- (hsrm) **Own personal experience** Made during Wintersemester 24/25 (HochschuleRheinMain)

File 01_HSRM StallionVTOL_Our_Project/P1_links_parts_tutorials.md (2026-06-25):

# 🔗 Links – Parts & Tutorials

---

## 🖨️ Print Settings & 3D Modeling

- [LW-PLA Print Settings – Flightory](https://flightory.com/lw-pla-print-settings/)
- [Editing STL Files in Fusion 360 – All3DP](https://all3dp.com/2/editing-stl-in-fusion-tutorial/)
- [Mesh to Body in Fusion 360 – YouTube](https://www.youtube.com/watch?v=tVGtG-UjlYg)

---

## 🚁 Drone

- [Stallion VTOL Pack – Flightory Product Page](https://flightory.com/product/stallion-vtol/)

---

## 🔧 Components

| Part | Options & Links |
|---|---|
| **Motors** | Emax ECOII 2807 1300KV [→](https://emaxmodel.com/products/pre-order-emax-eco-ii-series-2807-1300kv-1700kv-1500kv-brushless-motor-for-rc-drone-fpv-racing) / T-Motor F90 1300KV [→](https://amzn.to/3WavDu2) |
| **Propellers** | 7×4 / 7×5 / 7×6 (two CCW, one CW) [→](https://amzn.to/4eQ92Ku) |
| **Servos** | PowerHD 1810MG [→](https://botland.store/micro-servos/2304-servo-powerhd-hd-1810mg-micro-6939570720114.html) / GDW DS041MG [→](https://pl.aliexpress.com/item/1005002558931340.html?gatewayAdapt=glo2pol) |
| **ESC** | Emax Formula 45A BLHeli32 [→](https://emaxmodel.com/products/emax-formula-series-45a-esc-support-blheli_32-2-5s) / Lumenier 51A [→](https://www.getfpv.com/lumenier-51a-blheli-32-32bit-2-6s-w-telemetry.html) |
| **Battery** | 4S (max 4S3P 10.5Ah Li-Ion) or similar LiPo [→](https://amzn.to/45eRkMs) |
| **Bearings** | 2× 3×8×4mm Flange Bearing [→](https://www.avidrc.com/product/1/bearings/819/3x8x4-Flanged-Metal-F693ZZ-bearings.html) |
| **Screws / Nuts / Washers** | M3 screws, nuts, and washers |

---

## 📦 Base Package Components

| Part | Options & Links |
|---|---|
| **Flight Controller** | Speedybee F405 Wing or any Mavlink FC [→](https://amzn.to/3RjvlOB) / [→](https://amzn.to/4caIYI8) |
| **GPS** | Matek M10Q or similar (with compass) [→](https://amzn.to/3XiN9gR) |
| **Servos** | 4× Corona 929MG Metal Gear or similar [→](https://amzn.to/3RgTPIs) / [→](https://hobbyking.com/en_us/corona-929mg-metal-gear-servo-2-2kg-0-10sec-12-5g.html) |
| **Receiver** | Matek R24-D ELRS or similar [→](https://amzn.to/3Vxpub9) |
| **FPV Camera + VTX** | Walksnail Avatar HD Kit V2 [→](https://caddxfpv.com/collections/dual-antennas-version/products/walksnail-avatar-hd-kit-v2-dual-antenna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) / [→](https://caddxfpv.com/collections/single-antenna-version-kit-2024/products/walksnail-avatar-hd-kit-v2?aff=167) |
| **FPV Goggles** | Walksnail Goggles X or matching VTX [→](https://caddxfpv.com/products/walksnail-avatar-hd-goggles-x?aff=167) |

---

## ⚙️ Tuning & Configuration

- [ArduPilot – QuadPlane VTOL Tuning](https://ardupilot.org/plane/docs/quadplane-vtol-tuning.html)
- [T-Motor Multicopter Configurator (Prop / Motor / ESC)](https://www.premium-modellbau.de/t-motor-konfigurator-fuer-professionelle-multicopter-setups-motoren-regler-propeller)

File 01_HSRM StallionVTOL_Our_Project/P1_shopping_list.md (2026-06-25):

# 🛒 Our Shopping List – Optimized Parts

The components below are **not** the standard Flightory recommendations. We deliberately chose upgraded or alternative parts to improve payload capacity, thrust, and overall performance.  

| Part | Price | Weight | Notes | Link |
|---|---|---|---|---|
| **Motor** (×3) | €31 each | 69.2g | KV1350 variant preferred | [→](https://www.mepsking.com/tmotor-velox-v3008-cinematic-fpv-drone-motor.html) |
| **Propeller** (×2) | €3 each | 10.51g each | 8-inch 3-blade, M5 screw | [→](https://www.fpv24.com/de/gemfan/gemfan-cl-8040-cinelifter-durable-freestyle-3-blatt-8-zoll-black) |
| **Servo – Tilt** (×2) | €5.59 each | 10g each | 12×24×23mm | [→](https://pl.aliexpress.com/item/1005002558931340.html?gatewayAdapt=glo2pol) |
| **Servo – Flight Controls** (×4) | €5.99 each | 12g each | Corona CS929MG metal gear | [→](https://www.vgr-technology.de/p/corona-cs929mg-cs-929mg-metall-getriebe-servo-2-2kg-0-10sec-12-5g) |
| **Battery** | €120 | 612g | Zeee 4S 6200mAh LiPo | [→](https://www.amazon.de/Zeee-6200mAh-Stecker-Hardcase-Modelle/dp/B0B92PTQ4R) |
| **ESC** (4-in-1) | €120 | 17g | T-Motor F55A Pro II, 30.5×30.5mm mount | [→](https://www.premium-modellbau.de/t-motor-f55a-pro-ii-esc-55a-4in1-2s-6s-dshot-blheli-32bit) |
| **Flight Controller** | €75 | 7.4g | T-Motor F7, 30.5×30.5mm mount | [→](https://www.fpv24.com/de/t-motor/t-motor-f7-fpv-fc) |
| **GPS** | €50 | 8g | Matek M10Q-5883, 20×20mm | [→](https://www.fpv24.com/de/matek-systems/matek-systems-gps-kompass-m10q-5883) |
| **Receiver** | €22 | 3g | Matek ELRS 2.4G Dual | [→](https://www.rotorama.de/product/matek-elrs-2-4g-dual) |
| **FPV Camera + VTX** | €185 | ~22.6g | Walksnail Avatar HD Kit V2 Dual (camera 7.2g + VTX 15.4g) | [→](https://www.fpv24.com/de/walksnail/walksnail-avatar-hd-kit-v2-dual-antennas-version) |
| **FPV Goggles** | €255 | – | Walksnail Avatar HD Goggles L | [→](https://www.fpv24.com/de/walksnail/walksnail-avatar-hd-fpv-videobrille-goggles-l) |
| **Total (excl. goggles)** | **~€689** | **~802g** | Motors ×3, Propellers ×2, Tilt Servos ×2, FC Servos ×4, Battery, ESC, FC, GPS, Receiver, FPV Kit | |

### 🧰 Additional Items

| Item | Quantity |
|---|---|
| CA Activator | 1–2 cans |
| CA Glue | 2× 20g tube |
| M3 Threaded Insert | 45 pcs |
| M3 Screw | 55 pcs |
| M3 Nut | 15 pcs |
| Polyester CA Hinge 25×20mm | 30 pcs |
| Pen Spring | 5 pcs |
| Velcro Strap | 5 pcs |
| Servo Extension Cable | 10 pcs |
| LW-PLA (2.85mm, Natural) | 1 roll (750g) – [colorfabb.com](https://colorfabb.com/lw-pla-natural) |

ℹ️ **Disclaimer:** Some materials were provided by our university (Hochschule RheinMain) and are therefore not listed here. The shopping list reflects only what was independently purchased.

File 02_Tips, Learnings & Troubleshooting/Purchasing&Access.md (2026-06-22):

##  Purchasing & Access Issues

### Can't access purchased files / no orders showing

**Problem:** Purchased files but the download area shows no orders.

**Fix:** Download links are sent to the email used at checkout. Check spam/junk folder. If ordered as a guest without an account, check email. Contact Flightory at contact@flightory.com — they respond gradually due to high email volume.

---

### Painful slow downloads that keep failing
**Fix (from Flightory):** Check if your browser is blocking pop-ups, which may prevent the download. Try a different browser, device, or network (e.g. mobile data). Email Flightory if nothing helps.

---

### T-Motor website — how to pay

**Problem:** T-Motor allows ordering without payment and gives no clear payment instructions.

**Community answer:** T-Motor also has an **AliExpress store** which is more reliable and straightforward to purchase from. Amazon sometimes carries T-Motor products from third-party sellers. Email T-Motor directly to ask about PayPal.

---

### Can't place order on Flightory website

**Fix:** Contact Flightory directly: https://flightory.com/contact

## 📝 Sources
```
Source: Discord Group, link: https://discord.com/channels/1235173288150437929/1277936960970690603
```

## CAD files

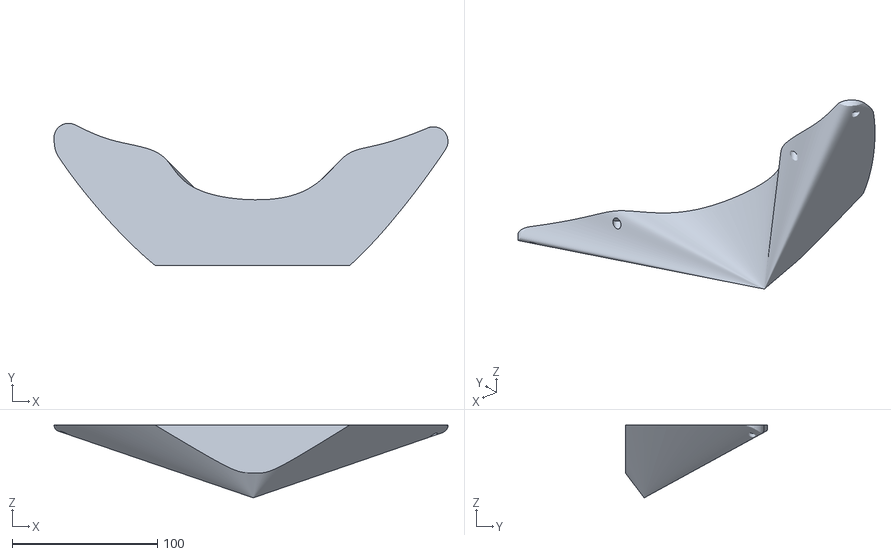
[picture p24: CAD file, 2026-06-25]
01_HSRM StallionVTOL_Our_Project/P1_stl_payload_case/front_lid.stl
270.8 x 97.9 x 50.0

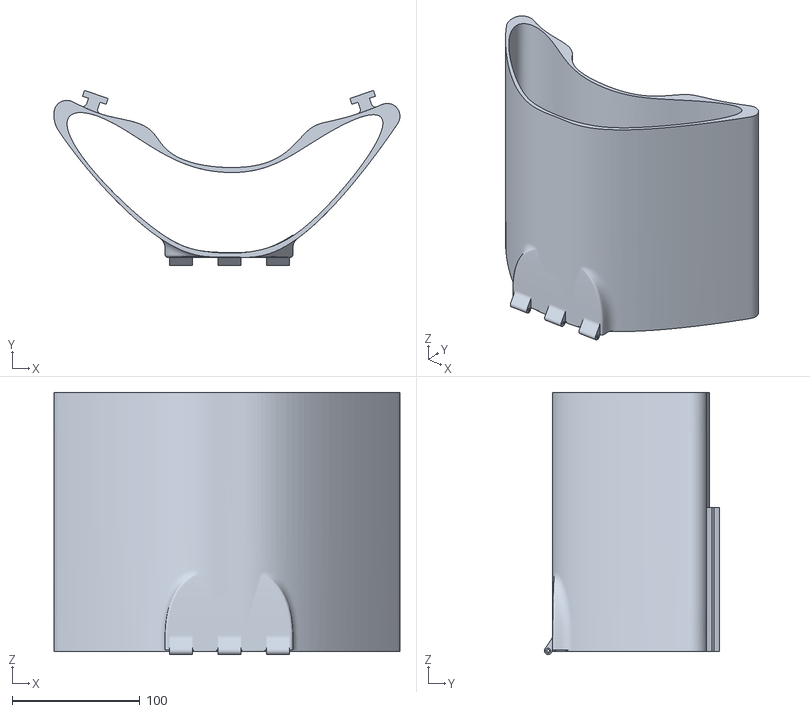
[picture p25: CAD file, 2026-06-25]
01_HSRM StallionVTOL_Our_Project/P1_stl_payload_case/case_middle.stl
270.9 x 137.2 x 205.2

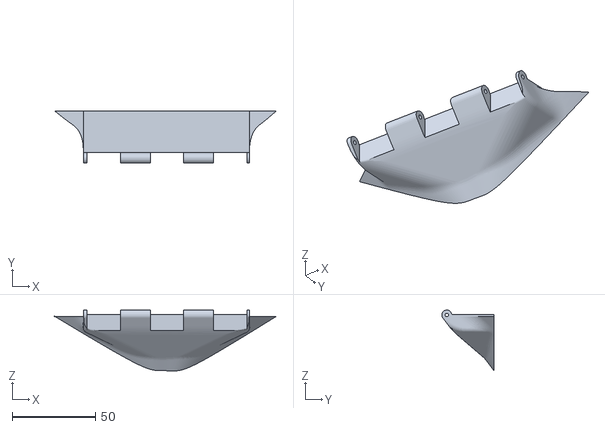
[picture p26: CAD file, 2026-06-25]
01_HSRM StallionVTOL_Our_Project/P1_stl_payload_case/front_joint.stl
133.5 x 31.5 x 36.7

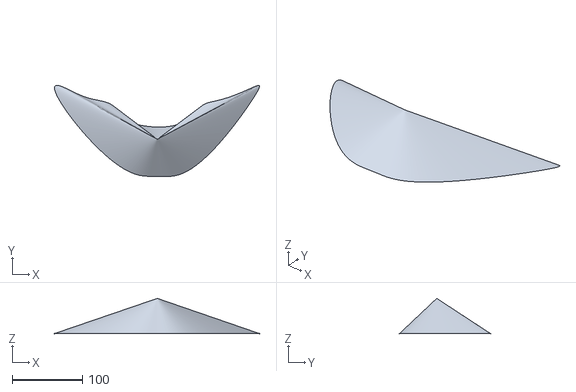
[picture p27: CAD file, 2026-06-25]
01_HSRM StallionVTOL_Our_Project/P1_stl_payload_case/back.stl
291.3 x 129.4 x 50.0

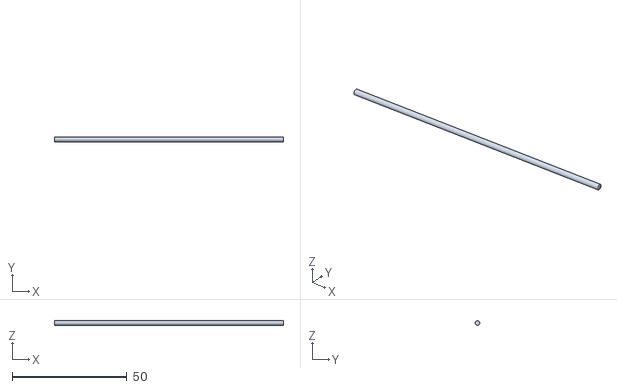
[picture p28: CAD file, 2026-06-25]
01_HSRM StallionVTOL_Our_Project/P1_stl_payload_case/pin.stl
100.0 x 2.00 x 2.00

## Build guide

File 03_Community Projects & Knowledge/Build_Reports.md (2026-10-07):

# 📋 Build Reports

This section collects build reports and project experiences found online. They provide practical insights into the building process, including lessons learned, challenges encountered, solutions found, and modifications made along the way.

The reports are intended as a reference and source of inspiration. Since they are based on individual experiences and different equipment, setups, and circumstances, not every recommendation will apply to every build.

## 💬 Forum & Blog Build Reports

* [Spitfire76's Build Log – Flightory Stallion VTOL](https://forum.flitetest.com/index.php?threads/spitfire76s-build-log-of-flightorys-vtol-stallion.75671/)
* [How to Build a 3D Printed Fixed-Wing UAV? | Talon 1400 Build](https://topdronesinfo.com/how-to-build-a-3d-printed-fixed-wing-uav-talon-1400-build/)

## 🐙 GitHub 

* [Engineering Archive covering multiple Flightory Drone Types](https://github.com/teamcorc/RC-Aircraft-Builds/tree/main/aircraft/flightory)

## 🎬 Video Build Reports & Tutorials

### ✈️ Flightory Talon 1400

* [Flightory Talon 1400 Build Tutorial – Part 1](https://www.youtube.com/watch?v=U0Qsgw7TUzI)
* [Flightory Talon 1400 Build Tutorial – Part 2](https://www.youtube.com/watch?v=ay6Tz3RohFc)

### 🚁 Flightory Stallion VTOL - Autonomous

* [Stallion VTOL Full Build Playlist](https://www.youtube.com/playlist?list=PL0V78eTdTTFGM4ZsZB-8frSqBhW0S1qe1)

### 🛠️ Full Beginner's Guide Flightory Stallion VTOL 

* [Part 1 – 3D Printing & Assembly](https://www.youtube.com/watch?v=75mRBMRqSeE)
* [Part 2](https://www.youtube.com/watch?v=D3_zBNBu3qo)
* [Part 3 – Final Assembly & Pre-Flight Checks](https://www.youtube.com/watch?v=thHDy3jc1nU)
* [iNav Setup – Stallion VTOL](https://www.youtube.com/watch?v=B3aNtYs5-dk)

## 🌐 More Build Resources

Additional build experiences, discussions, and project documentation can be added here as they are found.

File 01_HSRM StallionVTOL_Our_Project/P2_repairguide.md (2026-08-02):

# 🚁 Stallion VTOL – Repair Guide

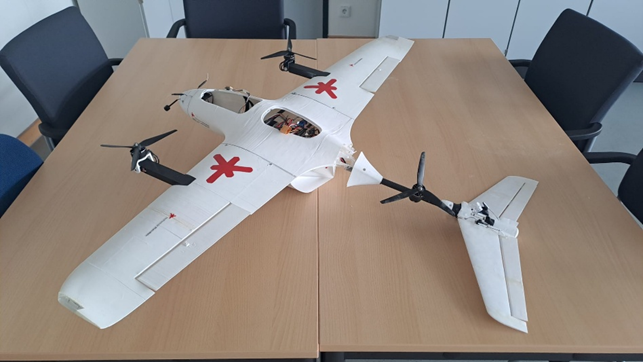
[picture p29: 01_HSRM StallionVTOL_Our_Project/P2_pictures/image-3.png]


## Fuselage
- Disconnect all electrical connections to tail and wings (connector plugs inside fuselage) 
- Remove V-tail and wing panels
- Carefully remove the damaged rear fuselage segment (cut or grind)
- Print a new segment
- Align new segment precisely, and bond structurally
- Reconnect all cables, reattach wings and V-tail

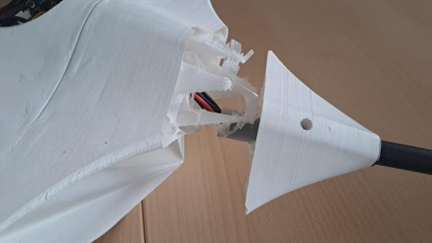
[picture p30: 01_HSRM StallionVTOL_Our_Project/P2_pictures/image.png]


## Tail
1. Remove servos carefully and disconnect the LED unit. 
2. Open the tail for access. Two options:
- *Option A:* Mechanically remove the tail elements to conserve the cables 
- *Option B:* Disconnect cables (by cutting) and reconnect later by soldering on modular connectors
3. Remove the tail
4. Print a new tail and equip with servos and LEDs. Two tail variants available:
- **"Existing" Variant 1** — heavier, greater structural strength, also serves as counterweight to the front-heavy battery
- **Variant 2** — lighter, lower structural rigidity
5. Reroute all Cables 
6. Mount Tail and secure all components 

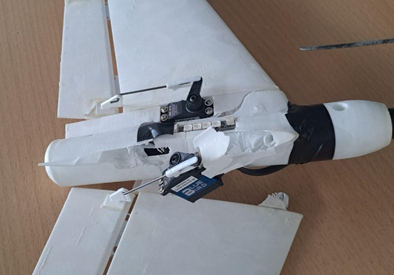
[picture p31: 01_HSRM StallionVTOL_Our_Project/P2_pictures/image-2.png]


## Full System Check
1. Verify functionality of all motors and propellers
2. Check structural integrity of the fuselage, thouroughly check for any remaining damage
3. Check stability of the full assembly, 
4. Check correct function of all electronics and RC channels. 
5. All subsequent flights to be conducted with minimum two people 

- pilot 
- spotter/technician

Optimally an additional person should available to act as "media" responsible - taking pictures / making videos as this could prove valuable for future documentation / evalution of crashs

*Source: Personal experience, HSRM Avionics project, Summer Semester 2025*

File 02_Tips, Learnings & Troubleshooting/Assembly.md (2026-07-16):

# Assembly

## Table of Contents
1. [Parts & Fit](#1-parts--fit)
2. [Carbon Fiber Tubes & Holes](#2-carbon-fiber-tubes--holes)
3. [Weight & Build Tips](#3-weight--build-tips)

## 1. Parts & Fit

### Screw lengths not specified anywhere in the manual (hsrm)
**Problem:** Flightory's documentation specifies which screw type (M3 etc.) but not the required lengths. There's no reference anywhere in the build guide.

**Fix:** Buy an assortment kit of M3 screws in multiple lengths (available cheaply on Amazon) and test-fit until the right length is obvious. Community recommendation: an M3 mixed-length set covers 95% of the build.

---

### Ball bearings not mentioned until you urgently need them (hsrm)
**Problem:** The flanged bearings for the tilt motor mounts are not mentioned in the build guide until you are mid-assembly and at the step that requires them.

**Fix:** Order the bearings (3×8×4 mm flanged, ×2) together with everything else at the start. Do not wait until you reach that step.

---

### Build guide is sparse — complex steps have no photos (hsrm)
**Problem:** Flightory's instructions are brief. Steps like connecting flight controls with hinges, servos, and pushrods are sometimes described in a single sentence with no photos.

**Tip:** Cross-reference with Flightory Discord and Facebook group for community-sourced photos and step-by-step clarifications. YouTube builds of the Stallion also help fill the gaps.

---

### Plan your internal modifications before printing (hsrm)
**Problem:** Reinforcing struts added inside the fuselage for a custom rail system blocked the carbon tube channels — only discovered after printing. Holes had to be drilled post-print as a workaround.

**Tip:** If modifying the fuselage interior, map out where all carbon tubes, cables, and components need to pass through before modelling the modification. The Flightory STEP files help significantly here.

---

### Fuselage segments too big for printer bed (dc)
**Problem:** Fuselage segments won't fit on the printer.

**Fix:** Split files are available. As described in the user manual, fuselage segments are available as whole sections AND split into left and right sides. Check the `FUSELAGE > R,L` folder in the file download.

---

### FUS ROOT glued to wrong part (dc)
**Problem:** FUS ROOT pieces accidentally glued to the fuselage instead of the wing.

**Clarification:** For the Stallion, FUS ROOT goes to the fuselage and WING ROOT goes to the wing (see manual pages 35 and 47). For the Talon, roots appear on both fuselage and wing in the instructions — check your specific model. Doubling up (gluing a root to both parts) can work and adds structural support for M6 bolts.

---

### Control horn placement direction (dc)
**Problem:** Unsure which way to orient control horns.

**Answer:** The straight edge of the control horn should be in line with the edge of the control surface. Holes should face toward the servo. 

**Tip:** Use hot glue instead of CA to attach control horns — easier to replace if they break without destroying the control surface.

---

### Servo won't fit in elevator slot — cable gets bent (dc)
**Problem:** Elevator servo can't be installed because the cable gets pinched.

**Fix:** Use a soldering iron at low temp (~250°C) to carefully melt a small cable notch into the plastic. Alternatively, use a small heated brass tube to make a clean hole. This is a standard technique for aftermarket modifications to printed parts.

---

### Pushrods — how to use them, do I cut them? (dc)
**Problem:** Pushrods seem too long.

**Answer:** Yes, cut the pushrods to the required length. The Z-shaped end clips into the control horn holes. 

---

### Servo deflection unequal — one side more than the other (dc)
**Problem:** Elevator at neutral is flush but has ~0.5" deflection one side and ~0.75" the other at full stroke.

**Fix:** Adjust the clocking of the servo arm forward from the 90° position. The servo arm angle at neutral is the key variable.

**Also:** In iNAV/ArduPilot you can adjust servo midpoint in the motor and output tab. Remember to enable live mode. Every servo is a few degrees off from factory — programming the neutral point is standard practice.

---

### Hinges — gap between aileron and wing (dc)
**Problem:** Nylon hinges leave a large gap between the aileron and wing surface.

**Fix:** Aim for as little gap as possible. Use thin CA/polyester sheet hinges (0.3mm) or TPU printed hinges instead of thick nylon hinges. These require no slot modification. Existing gaps can be sealed with "Blenderm" medical tape or similar modeling tape. If needed, cut the hinges to size to reduce the gap between two parts.

**TPU hinge STL:** https://www.printables.com/model/995250-tpu-hinge-flightory-stallion

---

### Torsion springs — what to use for wing clips (dc)
**Problem:** Torsion springs with pin are hard to find.

**Community solution:** Small hair clips (bobby pins style) from dollar stores work perfectly. Look for ~1.75" barrette-style clips. Some also sourced them from Amazon.

---

### Motor screws won't tighten (dc)
**Problem:** M2 screws spin freely and won't grip the motor.

**Fix:** The motor likely uses M2.5 screws, not M2. Try M2.5 screws. Check Datasheet or contact the motor supplier to confirm correct screw size.

---

### Printed servo horn broke — glued with CA (superglue) (dc)
**Problem:** A printed servo horn snapped but is still glued in place with CA.

**Fix:** Use flush-cut nippers to carefully cut away the main body, a small drill to core out the tab, then a combination of nippers and hobby knife to surgically remove the rest. Minor damage to the surface can be repaired with CA and paint.

**Prevention:** Use hot glue for control horns instead of CA — much easier to replace.

---

### M3 threaded inserts — what size screws to use (dc)
**Problem:** Unsure what M3 screw length to use with M3x5mm OD threaded inserts.

**Answer:** The OD (outer diameter) refers to the insert's width, not the screw length. Use M3 screws long enough to pass through the part and into the insert. A set of mixed M3 lengths from Amazon works well.

## 2. Carbon Fiber Tubes & Holes

### Carbon fiber tubes won't go into the holes / Spar holes too tight (dc) (fb)
**This is one of the most frequently reported assembly issues.**

**Fixes (in order of preference):**
1. Use a **sharpened brass tube** of the correct diameter as a hand reamer — grind a bevel on the inside edge and use it manually or in a drill motor to clear the hole.
2. Use a **long drill bit** of the correct diameter **by hand** (not powered) — cleans out the Z-seam or print debris that often blocks the hole.
3. Use a thin round file or wrap sandpaper around an object of similar/smaller diameter as the hole and ream manually. Check progress frequently!
4. **PTFE / Teflon lubricant spray** — helps tubes slide through tight holes without damaging plastic.
5. **KY Jelly** — community-suggested lubricant, dries with little residue, doesn't attack plastic.

> "I used an appropriate sized brass tube, sharpened it by grinding a bevel on the inside diameter, and used it in a drill motor to clean out the holes. Worked perfect."

**Do NOT:** Spin the carbon rod in a powered drill into the hole — the friction and heat can melt the plastic and permanently fuse the rod halfway in place.

---

### What size tubes / Carbon tube dimensions explained (dc) (fb)
**Problem/Question:** Carbon fiber tubes on Amazon or the BOM have multiple dimensions listed (e.g. 8x6x500mm or just 8x500mm) — which is which?

**Answer:** The dimensions refer to **OD (outer diameter) x ID (inner diameter) x Length**. 
- The Flightory BOM typically specifies OD and Length only (e.g., 8x500mm means 8mm OD, 500mm long). 
- Inner diameter and wall thickness are not specified because they do not affect the outer fit — either wall thickness works fine for this application.
- Exact pre-cut lengths are not usually sold; buy 1000mm (1m) tubes and cut them to size.

---

### 6mm carbon rod unavailable — can I use 7mm? (dc)
**Problem:** Only 7mm carbon rods available locally.

**Fix:** Modify the hole in the STL using a slicer modifier (fastest) or import into Fusion 360 / FreeCAD and widen the hole. TinkerCAD or Meshmixer also work. This is a 30-second job with a STEP file, harder with an STL.

**Fix for already printed parts:** Use a 7mm drill bit by hand (not powered), use a thin round file, or use a powered 7mm drill with extra care not to melt the plastic.

---

### Where to buy carbon fiber tubes (USA) (dc)
**Recommendations:**
- **Windcatcher RC** — most recommended by community, good selection and pricing
- **ReadyMadeRC** — https://www.readymaderc.com/collections/hardware/build-hardware/carbon-fiber-strips-tubes-spars/carbon-fiber-tubes
- **Amazon** — available, buy 1m lengths and cut to size. Not always in stock.

## 3. Weight & Build Tips

### What AUW (all-up weight) should I target? (fb)
**Reference weights shared by community:**

| Build | Weight (without battery) | Notes |
|---|---|---|
| Stingray VTOL (Bambu LW-PLA + PETG) | ~876g (printed parts only) | Reasonable |
| Stallion VTOL (LW-PLA/LW-ASA) | ~1,400–1,500g | Standard build |
| Stallion VTOL RTF with 6S 3300mAh | ~2,030g | Flown successfully |
| Stallion VTOL (PETG) | ~2,603g | Too heavy, marginal flight |
| Stork VTOL (ABS/ASA, non-foaming) | ~3,000g | Very heavy, CG problems |

> "If you lift off [in hover] and throttle is over 60–70%, you are in too heavy an area."

---

### Stallion VTOL — FC mount vibration concern (fb)
**Question:** Will vibrations from VTOL pods travel through the wing spars to the FC and affect barometer/gyro?

**Community answer:** This is a valid concern but in practice people mount directly on spars without reported gyro issues. Use foam dampening pads under the FC as standard practice. The bigger risk is electromagnetic interference from ESC wiring — keep power wires away from FC and GPS.

## 📝 Sources
- (dc) **Discord Group:** [Discord Flightory Group](https://discord.com/channels/1235173288150437929/1277936960970690603) 
- (fb) **Facebook Group:** [facebook.com/groups/flightory/](https://www.facebook.com/groups/flightory/)
- (hsrm) **Own personal experience** Made during Wintersemester 24/25 (HochschuleRheinMain)

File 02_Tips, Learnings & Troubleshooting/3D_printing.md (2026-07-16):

# 3D Printing Reference Guide

## Table of Contents
1. [Filament Choice & Settings](#1-filament-choice--settings)
2. [Bed Adhesion, Warping & Surface Finish](#2-bed-adhesion-warping--surface-finish)
3. [Print Failures & Quality Issues](#3-print-failures--quality-issues)
4. [Painting & Protecting Prints](#4-painting--protecting-prints)
5. [Wall Count and Infill](#5-wall-count--infill)

---

## 1. Filament Choice & Settings

### Active foaming vs pre-foamed LW-PLA — what's the difference? (fb)
**This is one of the most common points of confusion in the community.**
- **Active foaming** (eSun ePLA-LW, Colorfabb LW-PLA, Bambu PLA Aero): expands at high temperature (~230°C+). Print at 50–60% flow ratio. Much lighter than regular PLA — the whole point of using it.
- **Pre-foamed** (Polymaker PolyLite LW, Overture Air): comes pre-expanded. Prints like regular PLA at ~95–100% flow. **Not meaningfully lighter** — the community consistently reports poor results and excessive weight.

> "Foaming LW-PLA is very good and surprisingly strong when dialed in. And much lighter than Polymaker." 
> 
> "Polymaker LW-PLA is not really lightweight. It's lighter than PLA but far from a foaming LW-PLA like Bambu Aero or eSun LW-PLA with foaming agent."

**Recommendation:** Use an active foaming filament. Dry it before printing — moisture significantly affects these filaments. 1 day in a dryer is ideal; 3–4 hours at 55°C as a minimum.

---

### Flow rate — what setting to use for active foaming LW-PLA? (dc)
**Answer:** Active foaming LW-PLA foams at 230°C+, so it expands to fill the same volume at ~50–60% flow. Setting flow to 100% makes it heavy like regular PLA — you lose the weight benefit. Typical range: 0.48–0.60. Start at 0.55 and adjust.

**Warning:** Pre-foamed filaments (Polymaker PolyLite LW, Overture Air) are NOT the same — they print at 0.95–1.00 flow, like normal PLA. Mixing up these settings is a very common mistake.

---

### LW-PLA heat creep causing under-extrusion (dc)
**Problem:** LW-PLA (especially pre-foamed variants) is vulnerable to heat creep. Manifests as what looks like under-extrusion and adhesion problems — the filament occasionally stops going through the nozzle before starting again.

**Fix:** Clean the hotend and replace the cooling fan. Lower-density filament is more susceptible.

---

### LW-PLA printing speed — can you go fast? (dc)
**Problem:** Wanting to print LW-PLA faster than the manufacturer recommends.

**Answer:** Stick to the manufacturer's recommendations. For most LW-PLA (eSun, Colorfabb), 30–50 mm/s is safe. Printing at 195 mm/s caused major layer adhesion failures.

**Fix:** Drop print speed to 30–50 mm/s max in your slicer's filament profile. Set "max volumetric speed" in the filament settings to around 4–6 mm³/s as an easy cap.

---

### LW-PLA stringing — is it normal? (dc) (fb)
**Problem:** Active foaming LW-PLA produces lots of strings during travel moves.

**Answer:** Yes, this is completely normal and unavoidable with foaming filaments. It cannot be fully eliminated. It has a distinct look, smell, and feel.

**Fix (dc):** Set seam position to "nearest" or "back" in OrcaSlicer so strings hide in less visible spots. Clean up strings after printing with a metal file, utility blade, or nail. Printing one part at a time greatly reduces cross-contamination stringing.

**Post-processing (fb):** Use a nail, fine file, or hobby knife to clean strings. They come off easily and most interior strings don't matter structurally.

---

### LW-PLA oozing / continuous dripping at nozzle (dc)
**Problem:** Nozzle continuously oozes filament, making a mess.

**Answer:** This is a characteristic of active foaming filaments — it cannot be prevented.

---

### Weak walls / under-extrusion after seam (dc)
**Problem:** Walls are thin or missing right after the seam, making parts weak.

**Cause:** Travel stringing pulls filament out of the nozzle before the next wall starts.

**Fixes tried by community:**
- Turn off retraction entirely
- Add 0.6–0.7 extra prime amount
- Reduce retraction speed/length (don't eliminate it completely)
- Set seam to "random" so under-extruded spots appear in different places each layer, and the foamed material covers it
- For eSun LW-PLA on non-Bambu printers: 35 mm/s, 0.55 flow, half retraction speed/length, 0.6 extra prime

---

### LW-PLA clogged / won't extrude after sitting unused (dc)
**Problem:** eSun LW-PLA worked before but now won't come out. When it does melt, it's very liquid and brittle when cooled.

**Possible causes:** Wet filament (absorbed moisture), wrong flow settings.

**Fix:** Dry the filament first (55°C for 3–4 hours). Then check flow ratio — it should be 0.50–0.60, NOT 1.0. Foaming filament that is too wet behaves erratically.

---

### Best LW-PLA brand recommendations (dc)
**Community consensus:**
- **Active foaming (recommended):** eSun LW-PLA, Colorfabb LW-PLA, Bambu PLA Aero — all three are comparable in print quality and weight. eSun is most economical if bought in multipacks from their store.
- **Pre-foamed (NOT recommended):** Polymaker PolyLite LW, Overture Air PLA — heavier, prints like regular PLA, no real weight benefit.
- **LW-ASA:** Colorfabb LW-ASA / Bambu ASA Aero — better UV and heat resistance than LW-PLA. Requires sealed enclosure and carbon filter (fumes are toxic). Hardens significantly with acrylic/enamel paint.

---

### LW-PLA heat sensitivity — will it melt in the sun? (fb)
**Problem:** Polylight LW-PLA wings deformed (dimples, concave spots) after being left outside in Texas summer heat (32–43°C / 90–110°F) for just 15 minutes.

**Solutions:**
- Switch to **LW-ASA** (Colorfabb, Bambu ASA Aero) — far better UV and heat resistance
- **Regular ASA** (non-foaming) also works — plane will be heavier but will survive heat and sun
- **Paint with white acrylic/enamel** — reduces heat absorption and helps, but does not fully solve the problem with standard LW-PLA
- Do not leave printed LW-PLA parts in direct sun, hot cars, or hot enclosed spaces

---

### Can I print in regular PLA, ABS, PETG, or CF variants? (dc) (fb)
**Answer:** Short answer: not recommended, but it can fly with adjustments.
- Regular PLA, ABS, PETG, PLA-CF, ASA-CF are typically 1.5–3x heavier than LW filament.
- With standard PLA, the plane is likely unflyable as a VTOL and harder to hand-launch as a fixed wing.
- At 3 walls + 15% infill with ASA-CF, the weight is far too high. Even with LW filaments, people use 2 walls max.

---

### Cooling settings for LW-PLA vs LW-ASA (dc)
- **LW-PLA:** Needs lots of cooling. Run with doors open / lid off. Fan at 35–100%.
- **LW-ASA:** Needs a sealed enclosure, very little cooling (~25% max). Zero cooling causes poor layer adhesion. DO NOT open the enclosure while printing (toxic fumes).

---

### LW-ASA print settings — tips from Voron/CoreXY users (fb)
**For enclosed CoreXY printers (Voron, Switchwire, Trident) printing Colorfabb LW-ASA:**
- Start at **35 mm/s** — eliminates many variables.
- ASA behaves like ABS: warps, smells toxic, doesn't like drafts — enclosure is essential.
- Goal: single-wall prints at 50–55% of the weight of a standard PLA part.
- Low temperature + double wall gives a better-looking result while learning.
- The filament should be porous and slightly softer than PLA, but should NOT feel like paper.
- Start with an out-of-the-box ASA profile, use Flightory's ASA Aero settings as a guide, then adjust flow rate.

---

### Bambu ASA Aero — top surface tearing/rough finish (dc)
**Problem:** Top layers look rough or torn, especially on wing surfaces.

**Fixes:**
- Increase top layer count to 3–5 layers
- Increase fan speed slightly for overhangs
- Reduce top surface speed by ~10 mm/s
- Disable ironing (re-melting makes it worse)
- Rotate top layer angle (in OrcaSlicer) to shorten bridge spans
- Sand flush after printing — ASA-LW is very easy to sand

---

### Bambu ASA Aero — wall generator setting (dc)
**Problem:** Some parts (especially Lark boom mount) show gaps or missing walls.

**Fix:** Change wall generator to **Arachne** in slicer settings, and set slice gap radius to 0.

---

### Print settings — presets are a starting point only (fb)
**Key community wisdom:** Successful 3D printing comes down to one thing: realizing that two identical machines running the same production job require different adjustments. Take the time to calibrate the filament for your specific machine.

**What to do:** Use Flightory's print settings page as a starting point, then tune flow rate, temperature, and speed for your specific printer and filament batch.

---

### Bambu Lab printers — using Flightory presets (fb)
- **PLA Aero and Colorfabb LW-PLA on P1S:** Flightory presets work directly with excellent results.
- **H2D:** Copy settings from X1C profile manually; adjust print temp and flow rate slightly.

Note: you receive STL files, not .3mf — you must slice them yourself, it's not automatic.

---

### Spektrum UltraFoam LW-PLA — settings guidance (fb)
**Reported settings:** 0.6 flow rate, 250°C. FUS1L came out at ~11g. Active foaming settings from Flightory's website should work as a starting point.

---

### Printing multiple parts at once (dc)
**Warning:** For LW-PLA/ASA, print one part at a time. Printing multiple parts causes stringing between objects, material loss when hopping between surfaces, and thin walls or gaps around seams. Single parts also avoid collision spaghetti if one part detaches.

## 2. Bed Adhesion, Warping & Surface Finish

### Parts detaching mid-print / wobbling (dc)
**Problem:** Parts start fine but detach from the bed mid-print, causing spaghetti on later layers.

**Fixes:**
- Use a 5–8 mm brim with **zero brim gap** (the gap defeats the purpose)
- Apply glue stick to the print bed before each print — cheap paper glue sticks work fine
- Clean the plate with dawn dish soap and hot water between prints
- Smooth PEI plate + thin glue stick layer = most reliable combination

---

### ASA / LW-ASA warping / corners lifting (dc)
**Problem:** ASA corners peel off the bed, parts warp — especially in cold rooms.

**Fixes:**
- Sealed enclosure is essential
- Bed temp at 100°C (max for Bambu P1S)
- Turn off chamber fan completely (modify start G-code)
- Use Polymaker ASA rather than Bambu ASA if you have adhesion issues
- Dry filament before printing (wet filament worsens warping)
- Large brim (10 mm) helps
- If the room temperature fluctuates a lot, try to keep the room warmer

---

### Part warping — minor corner dip (dc)
**Problem:** A small corner of a fuselage section dipped/warped slightly.

**Fix:** Minor warping can be filed down on the outer portion before joining. If severe, reprint. Can also fill with body filler (Bondo Glazing & Spot Putty or German equivalent polyester filler like Presto) and sand.

---

### ASA welding to the print plate / won't release (fb)
**Problem:** LW-ASA sticks so hard to the textured PEI plate that it tears the surface on removal.

**Fixes:**
- Apply a thin layer of **glue stick** before printing — acts as a release agent
- Let the plate **fully cool** before attempting removal — ASA releases much better cold
- Try a **smooth PEI plate** instead of textured for ASA
- Some community members use specialty adhesive spray (3DJake AdheEasy) on smooth PEI — works well but may need bed heated to 90°C post-print to release

---

### ASA-CF on Anycubic Kobra — poor results (fb)
**Problem:** ASA-CF printing poorly on Anycubic Kobra S1.

**Tip shared:** Use 3 walls + 15% infill for nose, 1 wall + 3% for fuselage, 1 wall + 7% for the bottom fuselage section where the carbon tail tube inserts.

## 3. Print Failures & Quality Issues

### 3D printing inaccuracies — expect significant post-processing (hsrm)
**Problem:** Almost every printed part required manual correction before it would fit. Holes were too tight, channels were blocked, surfaces weren't flush.

**What helped:**
- Filing, drilling, and cutting after printing is normal — budget time for it
- CA-glued parts that don't fit correctly are very hard to separate without breaking them — dry-fit everything before gluing
- Some parts had to be reprinted entirely after failed gluing attempts

### Under-extrusion / voids in parts (fb)
**Causes:** Printing too fast, nozzle temperature too low, partially clogged nozzle, or using foaming settings on pre-foamed filament (or vice versa).

**Fixes:** For pre-foamed, print at ~100% flow. For active foaming, use 50–60% flow, 230–250°C, 30–50 mm/s. If too many voids remain, check if filament is dry, and increase temp by 5°C.

---

### Under-extrusion holes in parts — should I worry? (dc)
**Problem:** Printed parts show small holes from under-extrusion.

**Fix:** Adjust flow rate upward slightly (e.g., 0.98 → 1.20 flow ratio) to eliminate gaps. For small holes that remain: lightweight automotive body filler (Bondo Glazing & Spot Putty) works well. Don't worry about reprinting until you know the plane won't crash — epoxy/filler is enough for a first flight.

---

### Print slowing for overhangs then under-extruding when speed returns (fb)
**Problem:** Quality was good until the slicer slowed down for an overhang, then under-extruded when it resumed normal speed — leaving a weak band.

**Fix:** Set all speeds the same — remove variable speed for overhangs. This stopped the under-extrusion at speed transitions.

---

### Lines / ghosting above holes and cutouts (LW-ASA) (fb)
**Problem:** Wavy lines appear on wall surfaces just above where holes or cutouts rejoin.

**Fix:** This is called **ghosting** or **ringing** — caused by vibration from rapid direction changes. Reducing acceleration and jerk settings helps.

---

### Z-seam causing problems with carbon tube holes (dc)
**Problem:** A large Z-seam runs down every hole for carbon fiber tubes. Nothing fits — tubes broke three parts trying to force them in.

**Fix:** Use a long drill bit to drill through the holes with the correct diameter (4 mm, 6 mm, 10 mm) to clean out the seam material. Alternatively, wrap sandpaper around a tube the same size and ream it by hand. Do not use the drill spinning or the plastic may melt.

---

### Carbon fiber tube holes too tight / Spar holes not fully formed (dc) (fb)
**Problem:** Carbon fiber tubes won't go into the printed holes or wing spar holes are incomplete.

**Fixes:**
- Use a sharpened brass tube or correct drill bit of the correct diameter **by hand** (not powered) to clean/widen the hole slightly.
- Grind a bevel on the inside of a brass tube first to act as a cutter, or wrap sandpaper around a tube of the same diameter and ream manually.
- **Do NOT** attach the rod to a drill and push it in while spinning — the friction can melt the plastic and permanently fuse the rod halfway in.

---

### Print fails at ~87% every time (fuselage parts) (dc)
**Problem:** Dreamer NX printer with Flashprint slicer — prints stop at the same point with "print file error."

**Possible causes / fixes:** Check SD card health, prevent computer sleep if printing via USB, or check STL files for non-manifold edges (Windows 3D Viewer can auto-fix these).

---

### Printing hatch parts — sways / wobbles during print (dc)
**Problem:** Hatch pieces wobble during printing, causing poor quality on upper layers.

**Fix:** Use a brim and try turning off the fans. For tall, thin parts: print the split versions to halve the height. Reduce travel speed to minimise kinetic energy.

---

### Wings not aligning / misaligned print layers (dc)
**Problem:** After printing, wing sections don't align to each other.

**Fixes:** Use a brim without gap spacing, use bed adhesive, turn off chamber fan if enclosed, keep the printer somewhere warm if open, use a higher bed temperature, and dry the filament.

---

### Part orientation — how to orient for printing (dc)
**Always check the manual for recommended print orientation.** Wrong orientation is a common cause of print failures and weak parts.

---

### Klipper / BLTouch Z-offset keeps resetting (dc)
**Problem:** On Ender 3V3 SE with Klipper, BLTouch keeps resetting Z-offset.

**Partial fix reported:** Save the Z-offset value directly to the config file. Check Klipper forums for BLTouch-specific config.

---

### Creality K1C — no good LW-PLA preset in Creality Print (fb)
**Problem:** Creality Print doesn't have a dedicated LW-PLA preset; results are very poor.

**Fix:** Use **OrcaSlicer** instead — it has better LW filament support. Or manually create a profile based on Flightory's recommended settings.

---

### CF filament too brittle / breaking in extruder (fb)
**Problem:** CF filament breaks in the extruder before printing.

**Main cause:** Moisture. Dry the filament thoroughly before printing (55–65°C for 4+ hours).

## 4. Painting & Protecting Prints

### Can LW-PLA parts be painted without adding too much weight? (fb)
**Yes — lightly.**
> "Anything works on LW-PLA and LW-ASA — it's like canvas. It is chemically stable so most paints will not affect it."

**Lightweight options:**
- **Cerakote** — goes on very thin, minimal weight added, very durable.
- **Water-based spray paint** — one coat is sufficient (e.g., Blick water-based spray used on Moose: "matte finish is beautiful").
- **Acrylic enamel spray** — strengthens surface significantly, good UV protection.
- **High-pigment paints** — use less product to achieve coverage.

**Tip for finishing:** Sand parts smooth first to reduce the amount of paint needed for coverage.
> "Paint and filler add quite a bit of weight. Your best bet is sanding the parts smooth and then using a high-pigment paint to reduce the amount you need."

---

### What acrylic filler primer works in the USA? (fb)
**Community suggestions:**
- Any acrylic-based filler primer works — look for lightweight sandable primer spray cans.
- Sand to smooth first, then apply a thin coat of primer before painting.
- Rust-Oleum acrylic enamel and Duplicolor are both community-confirmed options.

---

### Will paint protect LW-PLA from melting in the sun? (fb)
**Partial fix only.** White or light-coloured paint helps by reflecting heat. But standard LW-PLA will still soften in sustained direct sun exposure even when painted. For reliable heat resistance, switch to LW-ASA or LW-PLA-HT.

## 5. Wall Count & Infill

### Recommended wall count and infill (fb)
**Community consensus for LW filaments:**
- **Walls:** 1 wall for main airframe (wings, fuselage). 2 walls for reinforced areas. 3 walls makes parts noticeably stronger but significantly heavier.
- **Infill:** 3–7% gyroid or similar. Use 15% only for small structural parts (nose, mounts).
- **Top/bottom layers:** 2 standard, up to 3–5 if surface quality is poor.

> "3 walls 15% infill with ASA-CF is way too much weight. Even with LW filaments, people use 2 walls max."

## 📝 Sources
- (dc) **Discord Group:** [Discord Flightory Group](https://discord.com/channels/1235173288150437929/1277936960970690603) 
- (fb) **Facebook Group:** [facebook.com/groups/flightory/](https://www.facebook.com/groups/flightory/)
- (hsrm) **Own personal experience** Made during Wintersemester 24/25 (HochschuleRheinMain)

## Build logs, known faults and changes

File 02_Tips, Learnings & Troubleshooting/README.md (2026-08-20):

# 🔧 02 – Tips, Learnings & Troubleshooting

This folder is a growing collection of practical tips, best practices, fixes, and workarounds gathered while working with Flightory.

If you ran into a problem and figured it out — document it here, contributions from personal experience, community members, and online sources are all welcome.

## 📂 What You'll Find Here

- General usage tips and best practices
- Print settings and hardware recommendations
- Step-by-step fixes for known issues
- Workarounds for bugs and firmware quirks
- Installation, setup, and configuration problems
- Performance issues and solutions

## 📁 Folder Structure  

| File | Description |
|---|---|
| 🖨️ [3D_printing](./3D_printing.md) | Filament choices, print settings, print failures, painting/protecting printed parts |
| 🔧 [Assembly](./Assembly.md) | Build fit issues, general build tips, weight targets |
| ⚙️ [Components](./Components.md) | Part upgrades, sourcing, part related problems |
| 🔌 [Electronics&Avionics](./Electronics&Avionics.md) | Flight controllers, ESCs, motors/servos, GPS/receiver, battery/power, VTX/camera, wiring/connectors |
| 📁 [Files_CAD](./Files_CAD.md) | File formats, CAD/slicer compatibility, printer specs |
| ✈️ [Fixed_Wing](./Fixed_Wing.md) | Fixed-wing flight tips & issues |
| 💥 [Flight_Crash_Issues](./Flight_Crash_Issues.md) | Pre-flight safety, crash causes/case studies, crash repair steps, and post-crash checklists |
| 💻 [Flight_Software](./Flight_Software.md) | iNAV and ArduPilot setup, firmware flashing, servo/motor configuration, and tuning issues |
| 🛩️ [Model_Selection](./Model_Selection.md) | Model choice, skill level, budget, flight time |
| 🛒 [Purchasing&Access](./Purchasing&Access.md) | Buying/downloading files & parts issues |
| 🚁 [VTOL](./VTOL.md) | VTOL hover/transition problems |

## ⚠️ Disclaimer

This guide is intended as a helpful community knowledge base rather than an authoritative technical manual. Most entries are derived from discussions between users who shared their experiences and solutions. While care has been taken to preserve the original intent and context, I have not personally reproduced or validated every issue and fix. Always exercise your own judgment and refer to official documentation when in doubt.

## 🤝 Contribute

Solved something that wasn't documented? Learned something the hard way? Please share it — so others don't have to go through the same struggle.

For your input simply open an issue, i will then integrate it in the fitting section 😊

Include a source reference with each entry:

```
Source: Personal experience, tested on ...
Source: Discord, link: ...
Source: Facebook Group "Flightory Community", link: ...
```

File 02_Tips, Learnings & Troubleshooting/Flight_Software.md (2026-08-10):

# Flight Software

## Table of Contents
0. [General](#0-General)
1. [iNAV](#1-inav)
2. [ArduPilot](#2-ardupilot)

## 0. General 

### RC firmware update — official instructions don't work (hsrm)
**Problem:** The official GitHub instructions for updating the RC transmitter firmware (EdgeTX) failed.

**Fix:** Use the **Wi-Fi update method** instead — connect the transmitter to your Wi-Fi network and update over the air. This worked when the USB method didn't.

---

### GPS calibration — go outside, away from buildings (hsrm)
**Tip:** GPS calibration requires an open sky with no buildings or metal structures nearby. Compass calibration is sensitive to electromagnetic interference — move away from electronics, power cables, and metal objects. The university courtyard worked well for this.

## 1. iNAV

### iNAV version — 6.1 vs 9.0 (fb)
**Recommendation:** Use the latest stable iNAV version (currently 9.x). iNAV 8 had a known pitch oscillation bug. Version 9 has better VTOL support and bug fixes.

---

### Servos not moving in iNAV (dc)
**Problem:** iNAV outputs tab shows servos moving but actual servos don't respond. Multimeter confirms power to the ports.

**Fix:** Test in **Manual flight mode** — the only mode where sticks directly control servo movement. In stabilised/auto modes, the FC decides servo inputs and won't move them much while stationary (to avoid I-term windup). Also: check the servo is connected to the correct output number as assigned in iNAV.

---

### How to set up arming in iNAV (dc)
**Fix:** In the iNAV Modes tab, choose a channel (e.g. CH5) for ARM. Use the "auto-assign" or similar feature to let iNAV detect which channel moves when you flip the switch on your radio. Set the range bars so ARM is active when the switch is in the desired position. Check the Receiver tab to confirm all channels are moving correctly with stick input.

---

### iNAV VTOL mixer — sharing configs (fb)
**Question:** Can you share iNAV mixer screenshots for Stallion VTOL (both plane and quad profiles)?

**Community answer:** Mixer settings are highly specific to your build's servo angles and motor geometry. Importing someone else's diff/config file is not recommended — wrong tilt motor angles can damage the booms. Use the config in the manual as your starting point and adjust from there.

---

### VTOL rear motor overpowering front motors in iNAV (dc)
**Problem:** Rear motor dominates, iNAV can't correct. VTOL unstable.

**Fix:** Follow Bardwell's iNAV VTOL mixer tutorial on YouTube. The mixer needs to be correctly configured for the specific geometry of a tricopter VTOL. Also check that tilt servos are at exactly 90° (not slightly off) — even a few degrees causes yaw issues.

---

### VTOL spins in place / rocks in all directions while hovering (iNAV) (dc)
**Problem:** Stallion VTOL extremely unstable in hover, rocks in all directions.

**Cause:** Default PIDs are tuned for a smaller, lighter aircraft (like T1). The Stallion is heavier and bigger, so PIDs are off.

**Fix:** Search community PID tuning threads. 

The spin in place can also be caused by: wrong tilt motor angles, rear motor not straight, or wrong motor spin directions.

## 2. ArduPilot

### FC ships with iNAV — flashing ArduPilot is not straightforward (hsrm) 
**Problem:** The SpeedyBee F405 Wing (and similar FCs) are sold as "ArduPilot compatible" but ship with iNAV. ArduPilot cannot be flashed directly — you have to go through the iNAV Configurator first. This is not documented anywhere.

**Fix:**
1. Open iNAV Configurator
2. Go to Firmware Flasher
3. Select ArduPlane as the target firmware
4. Flash from there — not from Mission Planner directly

---

### QuadPlane parameters missing from stable ArduPilot release (hsrm) 
**Problem:** 11 hours lost because QuadPlane/VTOL parameters simply didn't appear in the stable firmware release. ESCs remained in standby (constant beeping), motor control was impossible. Nothing in the documentation explains this.

**Fix:** If VTOL parameters are missing or motors won't respond despite correct wiring, try the **latest unstable/beta firmware** version. The parameters had been removed from the stable release and were only available in beta at the time. Took minutes to fix once the root cause was known.

> "The parameters had apparently just been removed from the stable release. Not documented anywhere. A day of work lost on something that took minutes to fix once we knew."

---

### Sensor calibration sequence for ArduPilot VTOL (hsrm) 
Order of operations that worked for the HSRM build:
1. Flash ArduPlane firmware via iNAV Configurator
2. Connect via USB-C to Mission Planner
3. Write all QuadPlane/VTOL parameters
4. Go outside for GPS lock and compass calibration
5. Assign and test servo outputs
6. Flash RC transmitter and receiver firmware (EdgeTX + ELRS)
7. Bind transmitter and receiver (shared passcode for ELRS)
8. Test control surfaces — ailerons, V-tail, tilt rotors
9. Test motors last

---

### Strong yaw oscillations in hover — drone spins or rocks (hsrm) 
**Problem:** Significant oscillations around the yaw axis in QStabilize / QHover mode make the aircraft nearly uncontrollable.

**Fix:** Reduce yaw P-gain and feed-forward in the QuadPlane parameter set. Reference:
- https://ardupilot.org/plane/docs/quadplane-vtol-tuning-process.html
- https://ardupilot.org/plane/docs/tilt-vectored-yaw-tuning.html

First tuning session significantly reduced oscillations. Second flight (even in windy conditions) showed a clear improvement. Expect 2–3 tuning iterations before hover is clean.

---

### Yaw drifts back when stick is released (hsrm) 
**Problem:** After a yaw input, releasing the stick causes the aircraft to drift back toward the previous heading rather than holding position.

**Cause:** Yaw integrator or feed-forward not yet tuned correctly for the tilt-vectored yaw system.

**Fix:** Fine-tune the yaw parameter set further — specifically the I-term and feed-forward values. Check that tilt servo mid-points are exactly at 90° — even a few degrees of offset causes persistent yaw bias.

*(Not fully resolved by end of semester — flagged as an open tuning item.)*

 --- 

### Connecting ELRS/CRSF receiver to Matek F405 Wing V2 with Mission Planner / ArduPilot (fb)
**Problem:** Radio and receiver are bound but Mission Planner can't connect via MAVLink through a 2.4GHz ELRS receiver.

**Fix checklist:**
1. Cross RX→TX and TX→RX between receiver and FC
2. In ArduPilot, set the UART the receiver is on to RCIN (not Telemetry)
3. For MAVLink over ELRS, a separate UART is needed for the telemetry stream — ELRS RC and MAVLink can share a UART on newer ELRS firmware, but setup is complex
4. Check ELRS firmware supports MAVLink (requires ELRS 3.x+)

---

### Throttle visible in radio calibration but motors don't spin (dc)
**Problem:** Throttle channel moves in ArduPilot's radio calibration page, but motors don't respond.

**Answer:** In ArduPilot, the aircraft must be **armed** before throttle can be applied to motors. Use the left stick (not recommended) or a dedicated arm switch (recommended).
**Also check:** In Q-modes, check there are no remaining arming flags. GPS signal loss can block arming in some configurations.

---

### VTOL motor sequence (ArduPilot tricopter) (dc)
**Correct sequence for Stallion VTOL in ArduPilot:**
- Front Right → Motor A (Motor 1)
- Rear → Motor B (Motor 2)
- Front Left → Motor D (Motor 4)

---

### ArduPilot VTOL — one motor doesn't respond to throttle (dc)
**Problem:** Front right motor (Motor 1) only runs at arming min speed, doesn't increase with throttle. Responds correctly to pitch/roll.

**Common cause:** Motors and servos sharing the same hardware timer group — ArduPilot can't mix them on the same timer.

**Fix:** Ensure motors are on separate timer groups from servos. After fixing timer assignments, recalibrate.

---

### DShot1200 not recommended for VTOL (dc)
**Recommendation:** Use DShot 600 or DShot 300 on VTOL builds. DShot 1200 is unnecessarily fast and increases the risk of data loss from wire noise/interference.
"""

## 📝 Sources
- (dc) **Discord Group:** [Discord Flightory Group](https://discord.com/channels/1235173288150437929/1277936960970690603) 
- (fb) **Facebook Group:** [facebook.com/groups/flightory/](https://www.facebook.com/groups/flightory/)
- (hsrm) **Own personal experience** Made during Wintersemester 24/25 (HochschuleRheinMain)

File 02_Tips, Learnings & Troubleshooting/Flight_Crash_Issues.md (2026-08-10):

# Flight & Crash Issues

## Table of Contents
1. [Pre-Flight Safety](#1-Pre-Flight-Safety)
2. [Crash Issues](#2-motors--servos)
3. [Crash Repair ](#3-gps--receiver)
4. [Post Crash Checklist](#4-post-crash-checklist)

## 1. Pre-Flight Safety

## Pre-flight checklist — essential before any Flight. 

It's highly recommended to write your personal Pre-flight checklist fitting your Drone Model. 
That way Crashes / Issues can be minimized.

**Minimum crew recommended:** At least two people — pilot and spotter/technician. Camera coverage of every flight is strongly recommended for post-incident reconstruction.

## 2. Crash Issues

### Plane loops/noses dives immediately after hand launch (dc)

**Problem:** Pico Talon pitched sharply up after hand launch and nosed into the ground.

**Possible causes:**
- CG too far back (tail heavy)
- Wrong flight mode for maiden (do NOT use AutoTune on maiden — use FBWA or Stabilize)
- FC over-correcting the wrong direction (check gyro orientation in iNAV)
- Pitch/roll response swapped (elevon mixing issue on flying wings)

**Note:** Talons are particularly sensitive to CG and launch technique.

---

### VTX overheating causing potential RF interference (hsrm)
**Problem:** During the fourth flight test, the VTX was already hot before takeoff. A suspected signal interruption between transmitter and receiver occurred shortly after — possibly caused by RF noise from the overheated VTX.

**Fix:** Never take off with an already-hot VTX. Verify signal link quality in Mission Planner before arming. If RC signal quality is degraded, cool down and recheck before attempting flight.

--- 

### Drone yaws uncontrollably after takeoff — GPS mismatch (hsrm)
**Problem:** Immediately after takeoff in QHover, the drone yawed hard in one direction without any stick input and accelerated forward uncontrollably.

**Suspected cause:** GPS position mismatch. The FC attempted to correct to a position it believed it was at, but had never actually confirmed — because the pre-flight GPS check was disabled for test purposes and the FC may not have had a valid GPS lock at the moment of takeoff.

**Fix:**
- Always enable the pre-flight GPS check in ArduPilot — do not disable it even for short tests
- Verify GPS lock (solid green LED, 8+ satellites) before arming
- Never arm or take off without a confirmed GPS fix in position-hold modes (QHover, QLoiter)
- If GPS is not ready, use QStabilize mode instead — it does not rely on GPS position hold

---

### Motors cut out mid-flight — battery thermal/voltage issue (hsrm)
**Problem:** During a landing the motors cut out completely at ~2 m, causing the drone to fall straight down. Battery was found warm post-crash with cells unevenly discharged (~0.1 V difference between cells).

**Cause:** Battery delivering insufficient voltage under load — cells unevenly depleted, causing voltage sag to drop below the ESC's cutoff threshold.

**Fix:**
- Implement battery voltage logging (SD card in FC) so voltage history is available for analysis after any incident
- Monitor cell balance regularly — uneven discharge indicates a degrading pack
- Set a conservative low-voltage cutoff in ArduPilot (`BATT_LOW_VOLT`, `BATT_CRT_VOLT`) so the system warns before voltage becomes critical
- Replace any battery showing uneven cell discharge under load

## 3. Crash Repair 

### Crash repair — cutting damaged section (dc)

**Fix:** Use a hotwire foam cutter to cut the broken section off just before the nearest part line, then sand down the edge. Reprint only the damaged part.

Link: https://www.amazon.com/Cooltop-Styrofoam-Electric-Cutting-Cleaning/dp/B096SB93LQ/

---

### Repair sequence after structural crash damage
From the repair carried out after Flight Test 3:

1. Remove and label all electrical connections before starting any structural work
2. Remove damaged parts — cut or grind carefully to avoid damaging surrounding structure
3. Print or order replacement parts before disassembling further than necessary
4. Rebuild structurally first (fuselage, tail), then reinstall electronics
5. Run a full ground check of all motors, servos, and RC channels before closing the aircraft up
6. Do a CG check after reassembly — crash repairs can shift weight distribution

---

### Repair Guide Tail Replacement Stallion VTOL

Also see: 01_HSRM StallionVTOL_Our_Project/P2_repairguide.md

## 4. Post Crash Checklist

### Post Crash Checklist - essential after any incident (hsrm)
**Two crashes occurred in the same session.** The second crash happened in part because the team flew again after the first crash without a complete systems check.

**Rule:** After any crash or anomaly, do not fly again until:
1. Root cause of the incident is identified
2. All damage is assessed and documented
3. All affected systems are tested and confirmed functional
4. GPS lock is confirmed
5. All pre-flight checklist items are complete

### Document everything immediately after a crash (hsrm)
After any crash, before touching the drone:
1. Take photos of the drone in its crashed position
2. Note exact sequence of events while memory is fresh
3. Review any available video footage before discussing — video reconstruction is more reliable than memory
4. Check battery voltage and cell balance
5. Inspect all structural connections, motor mounts, and propellers before moving the aircraft

## 📝 Sources
- (dc) **Discord Group:** [Discord Flightory Group](https://discord.com/channels/1235173288150437929/1277936960970690603) 
- (fb) **Facebook Group:** [facebook.com/groups/flightory/](https://www.facebook.com/groups/flightory/)
- (hsrm) **Own personal experience** Made during Wintersemester 24/25 (HochschuleRheinMain)

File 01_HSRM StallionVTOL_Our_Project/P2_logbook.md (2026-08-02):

# 📓 Project Logbook — Stallion VTOL
*HSRM Avionics Module · Summer Semester Project 2025*

> **⚠️ Disclaimer:** This logbook is based purely on personal experience and is not a technical manual.
> It's meant as a reference for similar experiences — or simply as a loose guide.

## Starting point: 
We built the drone in Wintersemester 24/25 in the HSRM UAV Module and are now looking forward to improve it 

## 25.04.2025 First Overview 

### 📋 To Dos
- [ ] Self-locking nuts on propellers (UAV lab)
- [ ] Plan electronics modularisation / tidy electronics
- [ ] Order required parts → ask other group
- [ ] Charger / adapter for battery charging
- [ ] Carry out modularisation (UAV lab)
- [ ] Find suitable flight test location → model airfield
- [ ] First flight tests — gather experience on payload, speed, flight modes
- [ ] Parameter fine-tuning
- [ ] Plan a show-off day, compile guest list
- [ ] Documentation — comprehensive project summary: build steps, software settings, manual-style guide

### 📝 Modularisation Notes
**Goal:** Detachable wings, electronics decoupled as modules.

**Modularisation To Dos:**
- GPS, camera, RX mounted so they are removable
- FC & ESC as one decoupled module with stable attachment
  - Custom-fit enclosure / screw-mounted frame
  - Modularity + protection + stability
  - Padding? Cooling?
- Clear labelling — good organisation and documentation
- Battery, servo & LED pluggable out of FC
- Foam feet / mat on landing gear

## To Dos until 30.04.2025

| Task | Owner | Status |
|---|---|---|
| Ask other group about connectors / organise connectors | C | ✅ Done |
| Check battery charger, clarify motor direction in software | O | |
| Find model airfield with power outlet access | | |
| Define concrete flight test objectives | | |

## 30.04.2025

### ✅ Today
First successful test "flight" — new findings.

### 📋 Further To Dos
- [ ] Flexible cables for connection between plug connectors and ESC
- [ ] Rethink / reprint hatch closing mechanism
- [ ] Secure ESC and FC mounting
- [ ] Calibration
- [ ] Test / landing platform with luggage scale for thrust testing
- [ ] More detailed calculations on aircraft power
- [ ] Fleece/carpet on landing platform for soft landing

### 💡 Notes
- Battery charger can be borrowed from Mr. F
- **For 08 May:** Bring ropes to tie drone to table for indoor flight attempts

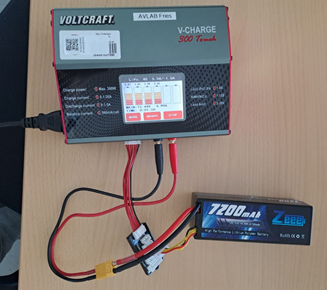
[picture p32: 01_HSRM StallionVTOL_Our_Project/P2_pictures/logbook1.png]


## 05.05.2025

### 📋 To Dos

| Task | Owner | Status |
|---|---|---|
| Parameter tuning | | ✅ Done (for now) |
| Create 10-min presentation for 08.05.25 | | ✅ Done |
| Write Aero report | | ✅ Done |
| 2nd flight for parameter tuning experience | | ✅ Done |
| Find new battery | | ✅ Done |
| Write and send shopping list | | ✅ Done |
| Order luggage scale | | ✅ Done |
| Fusion: landing gear design | C | |
| Fusion: ESC / FC housing | O | |
| Calculations: current and voltage over battery | | |
| Calculations: thrust / drag / lift | | |

**Presentation outline:**
- Topic and problem statement
- Progress so far
- Outlook

**Parameter tuning resources:**
- https://ardupilot.org/plane/docs/quadplane-vtol-tuning-process.html
- https://ardupilot.org/plane/docs/tilt-vectored-yaw-tuning.html

### ✈️ Flight Notes — 2nd Flight (windy conditions)
- Much more stable, no oscillation
- Better overall controllability
- Channel on remote is inverted — pitch for vertical now correct but inverted for horizontal
- Pitch & roll in vertical mode much smoother, more stable, better response
- Yaw around vertical axis works via stick — tilt rotors respond to tilt vectored yaw inputs
- **Issue:** When yaw stick is released, aircraft does not hold position — yaws back slightly / servos do not self-centre on the ground
- Battery hatch urgently needs adjustment
- Launch/landing platform would help observe flight behaviour without cargo
- Aircraft has great lift when facing into wind
- V-tail servos sound very strained → consider stronger servos
- Yaw parameter needs further adjustment

**Conclusion:** First parameter tuning was helpful.

### 🔋 New Battery Options

| Option | Capacity | Weight | Price | Link |
|---|---|---|---|---|
| 6S LiPo | 11,000 mAh | 1.35 kg | 199 € | [Conrad](https://www.conrad.de/de/p/tattu-modellbau-akkupack-lipo-22-8-v-11000-mah-zellen-zahl-6-25-c-softcase-xt90-s-2316803.html) |
| 6S LiPo | 17,000 mAh | 1.85 kg | 330 € | [Gensace](https://gensace.de/de/products/tattu-17000mah-22-8v-15c-6s1p-hv-high-voltage-lipo-battery-with-xt90-s-anti-spark-plug) |
| 6S LiPo | 23,000 mAh | 2.45 kg | 415 € | [Conrad](https://www.conrad.de/de/p/tattu-modellbau-akkupack-lipo-22-8-v-23000-mah-zellen-zahl-6-25-c-softcase-xt90-s-2316805.html) |

Additional parts needed:
- Charger adapter + extra cable for FC & ESC — [Conrad](https://www.conrad.de/de/p/reely-ladekabel-2x-bananenstecker-4-mm-1x-xt90-stecker-30-00-cm-re-6799044-2266348.html)
- GDW Servos — [AliExpress](https://de.aliexpress.com/item/1005008209269128.html)

---

Data for the motors (1350KV):





### ⚖️ Weight Overview (GF8040-3 props, 1350KV motors)

| Component | Weight |
|---|---|
| Empty drone | 2,203 kg |
| Cargo case | 0.480 kg |
| Current batteries | 0.553 kg |
| **Current AUW** | **3,236 kg** |
| With new battery (1.85 kg) | **4,533 kg** |

- Max total thrust at start (80% throttle): 7.79 kg at 124.5 A
- Cruise at 60% throttle: 61.5 A

## 08.05.2025 — Flight Day & Two Crashes

### ✈️ General
Test flight — overall stable and pleasant flying, no oscillation.

### 💥 Crash 1

**Sequence of events:** Motors cut out during landing after switching from QStabilize to QHover at ~2 m altitude. Drone fell straight down. Cargo case absorbed most of the impact. Rest of drone appeared externally undamaged.

**Fault investigation:**
- Battery connected to charger — approximately half full, cells unevenly discharged (~0.1 V difference). Battery was warm. Likely not delivering sufficient voltage → heat build-up.
- No error logs available.

**Suspected cause:** Battery overheating / voltage sag.

**Learnings:**
- Implement error logging
- New batteries with adequate voltage already on order

### 💥 Crash 2

**Sequence of events:** Pilot initiates takeoff with light throttle. Immediately after takeoff in QHover, drone yaws (without stick input) toward pilot and accelerates. Pilot attempts to control with one hand while deflecting with the other. Left wingtip hits a bench. Right wing hits pilot — right propeller stops against pilot's torso. Pilot reaches under right wing, slips. Drone yaws uncontrollably around pilot. Pilot attempts to hold right wingtip, slips again as wingtip hits a sign stand. Drone rotates around the stand at an angle, right motor collides with a stone ledge — servo mount breaks, motor points downward. Imbalance causes uncontrolled spinning on the ground. Pilot triggers emergency stop once recovered.

**Fault investigation:**
- No error logs available
- Intensive review of crash video footage
- Analysis of events and pilot account
- Damage documentation
- RC transmitter settings checked → all OK
- Gyro checked → correct readings, all OK

**Findings:**
- Uncontrolled and unintended flight attitude with unknown yaw to the right
- Unintended forward acceleration
- Pilot stood too close to drone → panic → instinctive unplanned reaction

**Suspected causes:**
- GPS position mismatch — FC attempting correction to a position it believed it was at
- No GPS log at startup — GPS pre-flight check was disabled for test purposes, possibly no GPS signal at takeoff

**Learnings:**
- Pilot must maintain minimum safe distance from drone at all times
- After any crash: no further flight until drone is fully inspected, root cause found, and fully resolved
- Enable pre-flight checks in firmware
- Create and implement a pre-flight safety checklist
- Minimum 3 people: pilot, support & camera operator — full video footage was essential for crash reconstruction

---

### 🔧 Damage Assessment & Repair To Dos

| Part | Damage | Action |
|---|---|---|
| Right wingtip | Bent / broken off | Glue |
| Both wing junctions | Small plastic connector broken | Reprint, remove old part with nail polish remover, glue new |
| V-tail (right side) | Broken | Full reprint + rebuild with stronger servos and carbon rods |
| Left wing front | Surface damage | Fill / sand |
| Left motor mount | Scratches | — |
| Left servo arm at motor mount | Broken | Remove and replace |
| Left propeller | Heavily damaged | Replace |
| Left LED cover | Broken off | Replace or reattach |

**Print order:**
- V-tail (complete)
- Wing mounts (both sides)
- Left motor mount
- Launch & landing platform

**Order list:**
- GDW servos
- Propellers
- LW-PLA filament

### 📋 To Dos Before Next Flight

- [ ] Repair all damaged parts
- [ ] Implement error logging
- [ ] Create pre-flight safety checklist (→ F.)
- [ ] Ground test all motors and servos
- [ ] Structural assessment of airframe
- [ ] Electronics assessment
- [ ] Electronics modularisation for clarity, easier fault-finding, and safety
- [ ] Dampen electronics mounting, line fuselage with fleece
- [ ] Safety goggles for pilot
- [ ] Verify whether idle thrust in QStabilize is too high

| Task | Owner | Status |
|---|---|---|
| Get familiar with Cura for print settings | C | |
| Place orders | | ✅ Done |
| Modularisation | | |
| Find replacement servos | O | ✅ Done |

## 12.05.2025

New To Do list moved to separate document.

## 15.05.2025

### ✅ Today
- VTX successfully connected to goggles — first functional check ✅
- New printed tail and electronics mount complete, surface sanded
- New tail assembly started (gluing, cutting carbon tubes)
- Electronics removed, old tail disassembly begun
- Wing repair (gluing, filling) and servo mount repair
- Battery hatch adjusted to fit
- Spare parts organised into new storage box

### 💡 Findings
- VTX gets very hot — reached 93°C within minutes, goggles triggered overheat warning
- Old batteries with XT60 connectors can be used to power goggles
- New tail printed with recommended settings — lighter and easier to work with than old tail
- Battery needs a holder so it doesn't slide around and damage fuselage from the inside

### 📋 Planning
- VTX cooling via airflow (design optimisation) / optimised position + cooling fan on the ground
- First ideas for electronics layout mapping

## 16.05.2025

### ✅ Today
- Cables shortened
- Left fuselage root repaired
- Banana connector layout planned
- Defective motor mount resolved
- Battery pad repaired
- Wings removed
- Preparation for electronics soldering
- PETG print jobs prepared and submitted

### 💡 Findings
- Detaching fuselage & wing roots is awkward — better to re-glue broken parts and reuse where possible
- Defective motor mount: better to replace and reinstall completely

### 📋 To Dos
- [ ] Design battery holder
- [ ] Design new hatches
- [ ] Develop fuselage cooling concept
- [ ] Install new electronics in new tail (servos, LED)
- [ ] Complete tail and attach
  - [ ] Renew LED cables
- [ ] Modularise and organise electronics:
  - [ ] New XT90 connectors on ESC
  - [ ] Desolder old ESC cables, solder new ones
  - [ ] Banana connectors
  - [ ] Adjust all cable lengths
  - [ ] Mount ESC and FC in enclosure

## 19.05.2025

### ✅ Today
- Glued wing screw mounts
- Desoldered old ESC cables
- Tidied ESC–FC connection (shortened cables)
- Soldered new battery connector
- Cura walkthrough 
- Submitted launch platform print job
- Received smaller PETG parts
- Soldered servo cables (wings)
- Soldered banana connectors to wing motor cables
- Slid housing over banana connectors on wings
- Removed rigid motor cables from tail
- Connected flexible motor cables for tail

### 💡 Findings
- Banana connector housing is tricky to slide on — requires the correct slot screwdriver (injury risk)
- Soldering small cables is difficult without a third and fourth hand
- Time passes faster than expected

### 📋 To Dos
- [ ] Banana connectors on tail motor cables
- [ ] Cable junction pieces on ESC
- [ ] Install new PETG parts
- [ ] Complete tail
- [ ] Extend GPS cable
- [ ] Design new hatches
- [ ] Design battery holder

## 22.05.2025

### ✅ Today
- Installed new motor mount
- Removed last broken wing mount
- Attached tail servos
- Drilled new servo cable holes in tail (carbon)
- Soldered motor cables to ESC

### 💡 Findings
- Nuts spinning freely in plastic is a problem — use threaded inserts or captive nut pockets in future designs

### 📋 To Dos
- [ ] Extend tail servo cables
- [ ] Solder LED connectors
- [ ] Route cables through tail
- [ ] Banana connectors on tail motor cables
- [ ] Finish gluing tail assembly
- [ ] Place and cable VTX and receiver
- [ ] Extend GPS cable
- [ ] Line fuselage body with fleece?

## 12.06.2025

### ✅ Today
- Reversed cable polarity
- New battery connector installed
- Pushrods fitted
- New ESC–FC connection

### 💡 Findings
- Remote no longer connects to receiver — unknown new firmware found on it, not flashed by us → other group had used the drone

### 📋 To Dos
- [ ] Landing gear
- [ ] Write pitch for project
- [ ] Find out why remote no longer connects and fix → reflash receiver and transmitter

## 13.06.2025

### ✅ Today
- Fault-finding on RC transmitter
- Reflashed transmitter
- Correct settings restored
- Pitch written

### 💡 Findings
- Other group had flashed their own software onto the transmitter — in doing so they disabled the internal RF module and switched to external (no external module was connected, so their group also had no connection). Fully resolved by reflashing and restoring settings.

## 23.06.2025

### ✅ Today
- Drilled holes in nose cover for antennas
- VTX installed
- Camera glued in place
- Nose assembly completed ✅
- Servo arm glued to motor

### 📋 To Dos
- [ ] Mount electronics box
- [ ] Line fuselage interior
- [ ] Define concrete flight test objectives
- [ ] Thrust test with luggage scale
- [ ] Review cable organisation
- [ ] Plan landing gear assembly
- [ ] File down landing gear (C.)
- [ ] Design hatch
- [ ] Design battery holder

## 27.06.2025

### ✅ Today
- SD card for error logs installed
- SD card for video storage installed in camera
- Electronics box mounted
- Battery holder designed → feet to be printed, idea: velcro on 2nd battery pad
- Cable organisation concept: front-to-rear routing with electronics feet
- Idea: ready-to-fly box

### 💡 Findings
- Real-time video transmission not possible — videos successfully saved to SD card in camera instead

### 📋 To Dos
- [ ] Test error log function → during weight test
- [ ] Define concrete flight test objectives
- [ ] Thrust test with luggage scale
- [ ] Review cable organisation
- [ ] Plan landing gear assembly
- [ ] File down landing gear (C.)
- [ ] Design hatch
- [ ] Find small hand fan (O.) → ✅ Found

## 30.06.2025

### ✅ Today
- Electronics connected
- Video recording to SD card tested → ✅ successful
- WiFi connection between drone and PC for Mission Planner → ✅ successful (motor test, servo trim, PFD, flight data remotely accessible)

### 💡 Findings
- Current issue: rear servo sensitivity too high

## 30.06.2025 — Wiring Reference

### Cable Connection Order
1. VTX *(optional, can be done later)*
2. GPS
3. LED 1
4. LED 2
5. LED 4
6. Close velcro fasteners
7. RX (receiver)
8. Servos *(see assignments below)*
9. Motor cables: Right, Left, Rear

### Notes
- Use masking tape to hold cables aside during assembly
- VTX, GPS, LED1, LED4 routed over carbon rods

### Servo Output Assignments

| Function | Servo Output |
|---|---|
| Aileron Left | 1 |
| Aileron Right | 2 *(inverted)* |
| V-tail Left | 3 |
| V-tail Right | 4 |
| Motor 1 (Front Right) | 5 |
| Motor 2 (Front Left) | 6 |
| Motor 4 (Rear) | 7 |
| Tilt Motor Left | 8 |
| Tilt Motor Right | 9 |

## 03.07.2025

### ✅ Today
- Pushrod re-glued
- CG (centre of gravity) tested and balance weight evaluated → approximately 350 g of additional tail weight needed

### 💡 Findings
- With heavier battery mounted at the front, CG shifts significantly forward → critical balance position, counterweight required

### 📋 To Dos
- [ ] Pack ready-to-fly box
- [ ] Evaluate error logs from 02.07 (Engineering Night)
- [ ] Improve rear servo deflection range

## Afterwards...

The documentation stops here, but the drone was set to fly again on a model airfield on 4th of July 2025.  
Sadly it rolled forward at the first throttle input during start and thus crashed.  
The reasons for the crash are unkown, though time pressure and stress, as well as the electronics probably played a part.  
Thankfully only the tail was damaged.
As our semester was over, we didn't have further time to work on the drone, but we wrote an  reparation guide for the next group that was going to take over our drone. 

see reparation guide in document xyz

## Much later afterwards... June 2026

I was close by and went to check on the drone, and found it to be completly repaired.  
It belongs to the Hochschule and might be used in courses as seen fit. As far as i could find out, it hasn't flown again since our last crash, but is mostly used for experience in software and as a model object.

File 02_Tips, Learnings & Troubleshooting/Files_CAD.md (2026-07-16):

# Files, Slicers & Printer Compatibility

### Do Flightory STL files import directly into Bambu Studio? (fb)
**Yes** — STL files open in Bambu Studio like any other STL. You slice them yourself using the recommended settings profile (downloadable from Flightory's print settings page). It is NOT automatic like Bambu's own ecosystem files.

---

### What file formats does Flightory provide? (dc)
**Answer:** Most parts are STL files. STEP files are available for some parts (primarily fuselage sections for Stallion). Wing parts are STL only. For full CAD assemblies, contact Flightory directly via email — they may be able to provide additional STEP files on request.

---

### STL vs STEP files — modifying parts is harder than expected (hsrm)
**Problem:** Flightory only provides some parts as editable STEP files. Parts only available as STL require a multi-step conversion to modify in CAD: import as mesh → repair mesh → convert to solid body → manually fix surface irregularities.

**Tip:** If you plan any modifications, identify which parts you need as STEP files early. Contact Flightory directly — they may be able to provide STEP files on request.

### STEP files not importing into Fusion 360 (dc)
**Fix:** Use "Insert Component" (not "Import"). This allows importing multiple STEP files into one assembly. Confirmed working with Flightory STEP files.

**Alternative:** FreeCAD can also import STEP files.

---

### Modifying STL files to change hole dimensions (dc)
**Options (easiest to hardest):**
1. **Slicer modifier** (Bambu Studio / OrcaSlicer) — add a modifier object over the hole, fastest method
2. **TinkerCAD / Meshmixer** — free, no-code, browser-based
3. **Fusion 360** — import as mesh, convert to body
4. **FreeCAD** — reliable for STEP and STL
5. **Solidworks** — possible but STLs are difficult; use STEP files where available

---

### Printer requirements — minimum bed size (fb)
Most Flightory fuselage and wing parts require at least a **220x220mm** bed. Some larger parts (wing halves on larger models) need 256x256mm or bigger. Always check part dimensions in the slicer before starting a print run.

---

### A1 Mini — can it print Stallion VTOL parts? (fb)
**Answer:** Most parts will NOT fit on the A1 Mini (180x180mm build plate). You would need to break parts down into smaller sections, which the files don't always support by default. A larger printer (P1S, X1C, or similar 256mm+ plate) is strongly recommended.

---

### Stallion VTOL — do I need both the base and VTOL files? (dc)
**Answer:** Yes. The VTOL pack is an extension — it does not include all parts needed to print the complete aircraft. You need:
1. Stallion base model files
2. Stallion VTOL extension files

---

### Is there a BOM with file descriptions for the Stallion? (fb)
**Answer:** The manual and website provide a parts list, but mapping every file to the build can be tricky from filename and folder structure alone. The community recommends going through the manual page by page and matching parts as you assemble. For VTOL, the VTOL extension pack changes which motor mounts and boom parts you need — cross-reference both manuals.

## 📝 Sources
- (dc) **Discord Group:** [Discord Flightory Group](https://discord.com/channels/1235173288150437929/1277936960970690603) 
- (fb) **Facebook Group:** [facebook.com/groups/flightory/](https://www.facebook.com/groups/flightory/)
- (hsrm) **Own personal experience** Made during Wintersemester 24/25 (HochschuleRheinMain)

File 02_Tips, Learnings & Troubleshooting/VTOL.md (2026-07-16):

# VTOL — Hover & Transition Issues

### Stallion VTOL wobbles badly when switching back to landing/hover mode (fb)
**Problem:** Takeoff and forward flight smooth, but switching back from FBWA to hover mode at low speed causes wobbling and instability — consistently reproducible.

**Likely causes and fixes:**
- **Don't transition in stabilised mode (Angle/Horizon)** — use Acro mode for the transition
- Make sure the nose is pointed into the wind during transitions — crosswind makes it much worse
- Reduce throttle to ~75% before transitioning back to hover (less propwash beating the wings)
- Gain altitude before transitioning — at least 150–200 ft so you can recover if something goes wrong

> "Don't transition in stabilised mode (angle or horizon). Use only acro mode."

> "Take her up pretty high on your first transition — 150–200ft — so you can recover if something doesn't seem right."

---

### VTOL drifts backward after lift-off (dc)
**Problem:** After fixing motor sequence, VTOL lifts off but immediately moves backward.

**Likely cause:** Ground effect / too close to the ground causes erratic behavior. The FC is fighting the air turbulence reflecting off the surface.

**Fix:** Give it more throttle to get higher altitude quickly. Also verify tilt servos are at exactly 90° — even slight misalignment causes drift.

---

### VTOL front motors / ESCs overheating in hover (dc)
**Problem:** Front two motors and ESCs very hot after 2-minute hover. Fine in manual (fixed wing) flight.

**Likely cause:** PIDs not tuned — motors working too hard to stabilise. Over-correction in hover causes sustained high current draw.

**Fix:** Tune PIDs for hover mode (Q-Stabilize / Q-Hover). Community references Bardwell's VTOL tutorial. Start with reduced P and feed-forward values.

---

### VTOL wobbling / oscillating on pitch during hover (fb)
**Problem:** Stallion VTOL oscillates heavily on pitch in hover mode.

**Causes:**
- Wrong motor/prop direction or FC configuration — a plane trying to rotate during hover is a dead giveaway
- PID tuning needed — especially if weight is significantly different from standard build
- In iNAV 8 this was a known bug; in iNAV 9 it's more likely to be wrong PIDs or CG

---

### Stallion VTOL can't lift off — needs 100% throttle (fb)
**Likely causes (in priority order):**
1. **Wrong battery voltage for the motors** — 1300KV needs 5S–6S
2. **Too heavy** — non-foaming filament, too many walls/infill, heavy electronics
3. **ESC calibration needed** — recalibrate ESCs after changing battery
4. **Wrong props** — too small or wrong pitch for the motor/battery combination

---

### VTOL transition — tilt motors not completing 90° transition (dc)
**Problem:** After transition command, tilt motors stop at 45° instead of completing to 90°.

**Answer:** In iNAV, VTOL mode transitions are not automatic — requires a 3-position switch operating 0° (hover), 45° (transition), 90° (fixed wing). Ensure switch is configured correctly and servo travel limits allow full 90° movement.

---

### VTOL rear motor — different prop size OK? (fb)
**Question:** Can the rear motor use a different prop size than the two front motors?

**Answer:** The FC controls each motor individually to maintain level flight. If the rear motor can generate enough thrust to keep the tail up, a different prop size should work. Run it on a separate ESC so the FC can control it independently for pitch authority.

---

### Stork VTOL — 3kg total weight with ABS/ASA and CG issues (fb)
**Problem:** Stork VTOL printed in ABS/ASA reached 3kg total. To balance CG, needed a 6S 4P 21700 battery pack, which won't fit with the battery cover.

**Root cause:** Non-foaming filament is 2x+ heavier than intended. The airframe is designed for LW filament.

**Options:**
- Reprint key weight-saving parts in LW-ASA or LW-PLA
- Accept the heavier build and use a battery that fits (may sacrifice CG)
- Extend the battery compartment or design a custom mount

---

### FC vibration from VTOL motors affecting gyro/baro (fb)
**Question:** Will vibrations from VTOL props travel through wing spars to the FC?

**Answer:** Use foam/rubber dampening pads under the FC as standard practice. This is common on all multirotors. The baro is more affected by pressure changes than vibration — cover it with foam. In practice, community members haven't reported major issues mounting on spars.

## 📝 Sources
- (dc) **Discord Group:** [Discord Flightory Group](https://discord.com/channels/1235173288150437929/1277936960970690603) 
- (fb) **Facebook Group:** [facebook.com/groups/flightory/](https://www.facebook.com/groups/flightory/)

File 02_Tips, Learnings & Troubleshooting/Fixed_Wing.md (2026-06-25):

# Fixed Wing — Flight Tips & Issues

### First transition tips for Stallion VTOL
> "Take her up pretty high on your first transition — 150–200ft — so you can recover if something doesn't seem right. Make sure you transition with a headwind or tailwind, no crosswind — it hates crosswind. Mine likes a tailwind on takeoff: much less power required and the transition is usually quicker. Whatever you do, don't accidentally hit the disarm switch — she will not re-arm in the air."

---

### Lark — landing hot / limited grass space
**Issue:** The Lark comes in fast on landing, challenging for small or obstructed grass areas.

**Community response:** The Lark is manageable but requires practice. If landing space is very limited, consider a VTOL model instead (Stallion, Stork VTOL) — they can land vertically anywhere.

---

### Pitch oscillations on fixed wing (dolphining)

**Problem:** MiniPlank oscillating on pitch after hand launch.

**Fix:** Cut pitch P-gain and feed-forward values in ArduPilot/iNAV. This is classic PID oscillation ("dolphining"). Also check that elevon mixing is correct — flaperon vs elevon configuration is a common confusion on flying wings.

## 📝 Sources
- (fb) **Facebook Group:** [facebook.com/groups/flightory/](https://www.facebook.com/groups/flightory/)

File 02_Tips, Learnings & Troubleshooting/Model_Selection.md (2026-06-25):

# Model Selection & General Questions

### Is the Stallion/VTOL suitable for a first build?
**Community consensus: these are experienced/expert builds.**

> "Hmm, this might not be the best thing to do for your first go around with planes and VTOLs. These are really considered experienced/expert builds. There are a lot of YouTube videos out there that explain the basics of RC plane builds."

**Suggested path for beginners:**
1. Learn basics with a foam trainer
2. Build a simpler fixed wing first
3. Progress to a Flightory model when comfortable with electronics and firmware

---

### Moose vs Stallion — launch and handling (fb)
**Question:** Is the Moose easier to hand-launch than the Stallion?

**Answer:** Yes. The Stallion's shape makes it hard to grip during a throw — two community members reported mishaps from it slipping. The Moose (twin-tractor design) is much easier to hold and launch. Generally: only the Pico Talon, Plank, and Lark are light enough for a one-handed throw; larger models need two hands.

---

### What budget do I need?
**No definitive figure given in the group**, but based on components discussed:
- Files: varies by model (check flightory.com)
- Filament: 2–4 kg of LW-PLA/ASA (~€25–40/kg for quality brands)
- Electronics (FC, ESC, motors, servos, GPS, receiver, VTX): €150–400 depending on spec
- Battery: €40–100
- Misc (CF tubes, hardware, glue, etc.): €20–50

Total estimate: **€300–600+** for a first complete VTOL build.

---

### Stallion VTOL — flight time expectations
**Realistic expectations from community flyers:**
- Hover-heavy flying: **10–15 minutes**
- Efficient forward flight (cruise-focused): **30–45 minutes**
- Optimised long-range build: **1–2 hours**

---

## 📝 Sources
- (fb) **Facebook Group:** [facebook.com/groups/flightory/](https://www.facebook.com/groups/flightory/)
